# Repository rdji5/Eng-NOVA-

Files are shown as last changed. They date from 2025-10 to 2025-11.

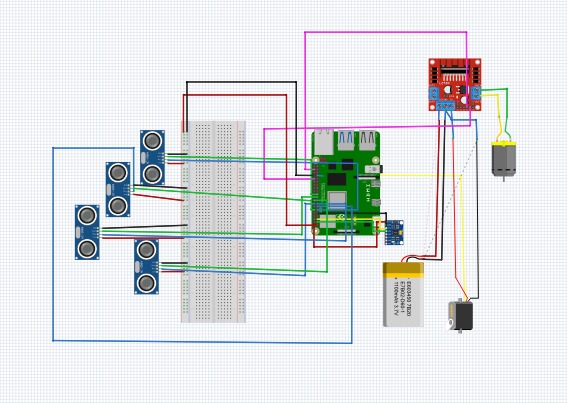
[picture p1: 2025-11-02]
Schemes/Electronic circuit.jpg

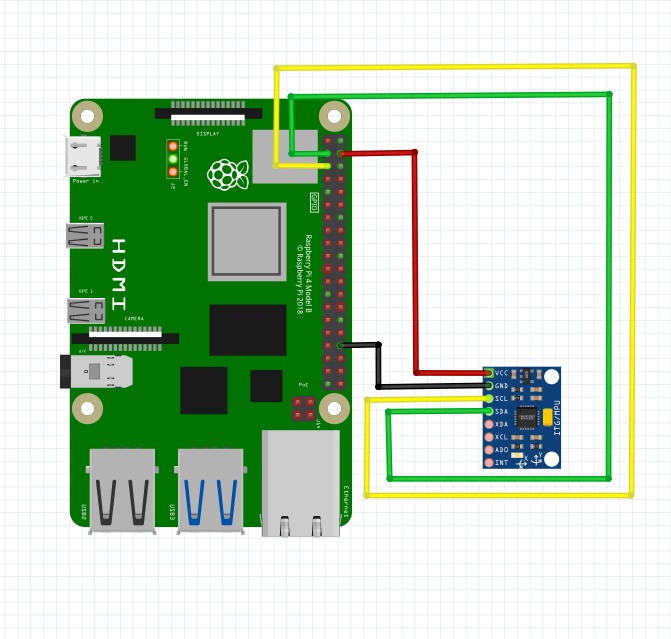
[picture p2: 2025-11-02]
Schemes/gyro.jpg

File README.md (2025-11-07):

# NOVA-Future-Engineers
### ***We Are The NOVA Engineers Team***

</p>
<p align="center">
Nova symbol
</p>

You can follow our team on social media to stay updated with our latest projects and achievements.
We share behind-the-scenes moments, progress updates, and highlights from our journey in robotics and technology.
Follow us on:

- Instagram [click here](https://www.instagram.com/nova_engineer3?)
- Facebook [click here](https://www.facebook.com/share/1Cu9dFqsgs/)

# Content
`3DModels` This folder has the robot’s 3D design and the final rendered version

`Car Pictures` This folder contains images of the robot car captured from six different angles, providing a complete visual overview of its design and structure

`Document (PDF form)` Includes a short document with project info from GitHub, saved as a PDF for A4 printing

`FlowChart` This folder includes flow diagrams that represent the logic and structure of the robot’s control system, showing how it interprets sensor data and executes movement decisions during tasks.

`Mechanical parts` parts Contains all mechanical parts used in our robot

`Problems`Documents the problems encountered during the project and their corresponding solutions.

`Tables` This folder includes all the tables we used in our project, such as time plans, task schedules, and data organization charts.

`Program` Contains all the code we wrote for the WRO 2025 Future Engineers and some charts that explain it.

`Robot-Photos` Includes multiple photos of the robot from various angles — top, side, and bottom — to provide a full visual overview of the design.

`Schemes`Drawings that show how the robot’s parts and wires are connected.

`To him work` Explains how the robot works

`Videos` Contains links to videos demonstrating how the robot performs and completes both missions successfully.

`Readme`This README file is divided into four main sections for better organization and understanding of the project’s structure.

  - [About Us](#part-1-about-us)
  - [Mechanical Design](#part-2-mechanical-design)
  - [Obstacle Management](#part-3-obstacle-management)
  - [Python Programming and Libraries](#python-programming-and-libraries)

***

### **Documentation Video (Youtube Link)**
This video is made with great care and dedication. It compiles all the information we included in the document
 you can [click here](https://youtu.be/SLGodH19J2s?si=U5ZjNuILHaWop1Gw ) to view the video we created.

***

# **Part 1: About Us**

## **This is our team**

We are three students from Hebron, Palestine, and we belong to the Programming and Artificial Intelligence clubs under the guidance of our coach, Abeer Al-Jabari. Our team was established with our participation in the Future Engineer program on September 1st. We have also previously participated in programming and STEM clubs.

## **Team name**
The name “NOVA” represents a new star that suddenly shines with renewed energy — symbolizing innovation, brilliance, and growth. It reflects our team’s spirit of creativity and ambition, as we strive to illuminate the field of engineering and technology with fresh ideas that drive progress and inspire excellence.

team photo

<hr>

## **Introduction to our team**

We are a group of passionate students participating in the Future Engineer competition  
Our goal is to learn, build, and showcase our creativity through robotics and programming
Our team works to distribute tasks in an organized manner that ensures the integration of efforts and the effective achievement of project objectives

**Raghad Wissam Al-Jaabari** 
- From Hebron
- 16 years old
- My hobbies are horse riding and badminton
-  Responsible for assembling the robot and executing programming tasks, integrating mechanical components with software to achieve the required performance and ensure the system operates efficiently
- ragadaljabari1@gmail.com

ragad aljabari

**Rasha Islam Al-Fakhouri**
- From Hebron
- 15 years old
- I love reading literature and philosophy, and I enjoy playing badminton
- Responsible for technical and organizational aspects, participated in presenting changes in project structures, in addition to continuous follow-up between stops to clarify the overall vision
- rashfakh9@gmail.com

Rasha AlFakhouri

**Layan Yousri Amro**
- From Hebron
- 14 years old
- my hobbies are sports and handicrafts
- She is responsible for documenting and writing reports on the project, and works on organizing the content and accurately documenting the work stages and results to present them in a professional and clear manner
- amrolayan95@gmail.com

layan amro

Despite our different ages and personal interests, we share a common passion: a love for technology and robotics, and a continuous desire to learn and improve. This passion drives us to participate in the Future Engineer competition and work together as a team

<hr>

### **Our Vision and Goal**
Our vision is to develop an intelligent robot capable of performing smart commands independently. We aim to build a system that can analyze its surroundings, make decisions, and complete tasks efficiently without direct human control. This project represents our first step toward creating innovative solutions that support our community and inspire future technological advancements Through this competition, we have gained valuable experience in robotics, programming, and teamwork. We also developed essential skills such as critical thinking, creativity, and planning In the future, we plan to use what we’ve learned to improve our projects, support younger students, and continue developing technologies that make a positive impact 

</p>

### **Work Schedule**

</p>

We developed a work plan to organize our steps and manage tasks within the team. It outlines what needs to be done each day, helping us set priorities, track our progress, and work with focus and teamwork to achieve our goals efficiently and accurately:
Plan_schedule

<hr>
</p>

# **Part 2: MECHANICAL DESIGN**
 ### **Firstly, the structure of the robot**
- **This car is a self-assembled (DIY) model that is built on a metallic chassis and uses an Ackermann Steering system to simulate the motion of real cars
The components of the car were connected and operated using a Raspberry Pi, programmed in Python to control movement and steering**

**This is the chassis**

<!-- Chassis Image -->
<table align="center">
  <tr>
    <td align="center">
      Chassis
      <p><b>Chassis</b>
    </td>
  </tr>
</table>

- Watch this video from the manufacturing source  [click here](https://www.youtube.com/watch?v=w_RRwR02S6U)

<div align="center">
  
</div>

<hr>
</p>

**Car size**

<!-- Car Size Image -->
<table align="center">
  <tr>
    <td align="center">
      Car Size
      <p><b>Car Size</b>
    </td>
  </tr>
</table>

<hr>
</p>

- **This car is not a remote-controlled vehicle; rather, it is an experimental platform developed to apply the principles of mechanics, control, and programming in the field of intelligent vehicles.
Thanks to the use of the Ackermann Steering system, the car replicates the actual steering mechanism of real vehicles, unlike the differential steering systems used in many traditional robots**
- **The car was entirely assembled and programmed manually as part of participation in the Future Engineer competition, using the Raspberry Pi platform**

<hr>
</p>

### **Ackermann Steering**

- **This is the servo that controls the wheels using the Ackermann Steering system:**

<!-- Ackermann Steering Image -->
<table align="center">
  <tr>
    <td align="center">
      Ackermann Steering
      <p><b>Ackermann Steering</b>
    </td>
  </tr>
</table>

Ackermann Steering Geometry: Precision Path Management
The chassis design of our autonomous vehicle is fundamentally based on the Ackermann Steering Geometry. We implemented a custom-modified version of this linkage system to ensure optimal cornering performance.
1. Principle of Operation
Unlike simpler steering methods (like skid steering), the Ackermann principle ensures that during a turn, the steering axis of all four wheels intersects at a single, momentary center point. This is achieved by ensuring the inner wheel (the wheel closer to the turn’s center) rotates at a sharper angle than the outer wheel.
This difference in rotation angle is critical because it forces the wheels to follow four distinct radii, allowing the inner wheel to travel a shorter path and the outer wheel a longer path, preventing any lateral slippage.
In our RWD system, the front wheels execute the steering motion around their respective pivots, while the single DC motor drives the non-steering rear wheels.

2. Mathematical Description (The Ideal Geometry)

<!-- Ackermann Image -->
<table align="center">
  <tr>
    <td align="center">
      Ackermann
      <p><b>Ackermann</b> 
    </td>
  </tr>
</table>

This diagram illustrates the Ideal Ackerman 
Steering Geometry. This geometry ensures that all four wheels, when steered, trace concentric circles around a single, common point, the Ackerman Center (C_a).
This fundamental relationship is governed by the vehicle's fixed dimensions—the Track Width (T) and the Wheelbase (W)—and the required steering angles:
cot(a_o) - cot(a_i) = T/W
Where a\_i is the inner wheel steering angle and a\_o is the outer wheel steering angle.
In this ideal setup:
The Inner Wheel Angle (a\_i) is always greater than the Outer Wheel Angle (a\_o) (a\_i > a\_o).
The lines drawn perpendicular to the plane of each wheel intersect precisely at C_a, ensuring all wheels roll without excessive side-slip.
Note: Real-world steering systems use a Modified Ackerman principle to optimize performance across the entire steering range, deviating slightly from this ideal formula.

3. Advantages for Our Robotic System:
Implementing the Ackermann geometry was a strategic choice that provided several specific benefits essential for the competition requirements:
Elimination of Tire Slippage: The main advantage is the prevention of tire scrubbing and slippage, which is crucial for accurate path following and maintaining maximum traction on the carpet surface.
Precise Path Management: The system offers high control over the front wheel's angle, allowing for precise steering control necessary to navigate between colored obstacles and adhere to strict course boundaries.
Single-Motor Compliance: This configuration naturally supports the requirement of using only a single DC motor for propulsion, simplifying the mechanical drivetrain while maintaining high maneuverability
Watch this video to understand the system [click here](https://www.youtube.com/watch?v=sF-PfAu50Fo)
<div align="center">
  
</div>

- **Wheels**

The wheels of this smart robot car have specific material and performance characteristics:
Wheel Rims (Hubs): The rim material is ABS (Acrylonitrile Butadiene Styrene). They are purely aesthetic
Tires (Rubber): The tire material is Rubber
Performance: The rubber material provides a large coefficient of friction and strong grip (traction) force. This design is crucial for stable and controlled movement across different surfaces
Internal Structure: All tires are internally fitted with a foam lining (insert). This foam insert provides necessary support and structure to the soft rubber tire, which is essential for consistent performance and shock absorption in RC and robot cars

<table align="center">
  <tr>
    <td align="center">
      Robot Car Gears
      <p><b>Wheels</b> 
    </td>
  </tr>
</table>

<hr>
</p>

- **Robot Car Gears**

In our project, we replaced the large gears with smaller gears in the robot car to control its movement speed
Gears are mechanical parts that transfer motion and rotation from the motor to the wheels, affecting both speed and torque
By replacing the large gears with smaller ones, we were able to reduce the car's speed and increase control accuracy, especially when performing precise movements or working with the distance sensor and relay.
- This modification helped make the car's movement more stable and safe, while maintaining the motor's power to drive the wheels smoothly

<!-- Additional Image -->
<table align="center">
  <tr>
    <td align="center">
      Additional Image
      <p><b>Robot Car Gears</b>
    </td>
  </tr>
</table>

***

<!-- BOM Image -->
<table align="center">
  <tr>
    <td align="center">
      BOM
      <p><b>BOM</b>
    </td>
  </tr>
</table>

### 📦 Bill of Materials (BOM)

| Part Name | Quantity | Description |
|---|---|---|
| Front metal chassis plate | 1 pcs | Front base for Ackermann steering system |
| Rear metal chassis plate | 1 pcs | Rear base for motor mounting |
| Electronics mounting plate | 1 pcs | Plate for Arduino / controller installation |
| Rubber wheels | 4 pcs | High-traction rubber wheels |
| Suspension spring | 1 pcs | Simple shock absorption system |
| Motor/servo mounting bracket | 1 pcs | Holder for servo or steering mechanism |
| Pulley / gear wheels | 2 pcs | Used in steering / drive linkage |
| Metal rods | Several | Used for steering linkage and frame connection |
| Bearings | Several | To reduce friction and improve smooth steering |
| Rod ends / ball joints | 4 pcs | Steering linkage endpoints |
| Servo mount brackets | 2 pcs | For attaching the steering servo |
| Metal steering arm | 1 pcs | Transfers servo motion to the wheels |
| Servo motor | 1 pcs | Controls front wheel steering |
| Spacer washers | 4 pcs | To maintain spacing between plates |
| Hex standoffs | Multiple | Structural support and spacing |
| L-shaped brackets | 2 pcs | Support brackets for structure |
| Screws (M2 / M3 assorted) | Set | Used for assembly |
| Nuts (M2 / M3 assorted) | Set | Used with screws |
| Metal shafts / pins | Multiple | For wheel/steering mechanism |
| Bearings housings | 2 pcs | Mounting for wheel axles |
| Plastic components | Several | Mechanical support parts |

<hr>
</p>

<table align="center">
  <tr>
    <td align="center">
      BOM
      <p><b>Brass Hex Standoffs</b> 
    </td>
  </tr>
</table>

- **Brass Hex Standoffs** 

These brass hex standoffs are used to elevate and support the Raspberry Pi and other electronic components.
They provide extra stability, improve airflow, and help organize the structure of the robot.
We used them to raise the robot’s layers securely, and they come in different sizes depending on the design requirements.

<hr>
</p>

### **Secondly, 3D model pieces**

- **3D machine**

**Creality Ender 5S1**

<!-- Creality Ender 5 S1 Image -->
<table align="center">
  <tr>
    <td align="center">
      Creality Ender 5 S1
      <p><b>Creality Ender 5 S1</b>
    </td>
  </tr>
</table>

The Ender-5 S1 is an FDM 3D printer with a stable cube-frame structure. It was designed to deliver better performance than previous models in the Ender series, offering faster and more responsive printing capabilities.
It is considered a great option for hobbyists and medium-level prototyping, thanks to its advanced features such as motion acceleration, direct-drive extrusion, and automatic bed-leveling support

#### General Specifications

| Specification | Value |
|---|---|
| Build Volume | 220 × 220 × 280 mm |
| Nozzle Diameter | 0.4 mm (standard) |
| Hotend Type | All-Metal |
| Max Hot-End Temperature  | 300 °C |
| Filament Diameter | 1.75 mm |
| Supported Filaments | PLA, PETG, TPU, ABS, ASA |
| Extruder Type | Sprite Direct-Drive Dual Gear Extruder |
| Max Printing Speed | 250 mm/s |
| Max Acceleration | 2000 mm/s² |
| Frame Type | Cube-frame Cartesian |
| Auto Bed Leveling | CR-Touch |

### Build Plate Specifications 

| Specification | Value |
|---|---|
| Build Plate Surface | Spring steel sheet with PEI coating (magnetic flexible plate) |
| Build Plate Size | 235 × 235 mm |
| Max Build Plate Temperature | Up to 110 °C |
| Heating Method | AC/Heatbed (magnetic heated bed) |
| Compatibility | Compatible with PC/PEI/Glass plates (optional upgrades available) |

### Tool Head Specifications 

| Specification | Value |
|---|---|
| Max Speed | 500 mm/s |
| Max Acceleration | 20 m/s² |

### Physical Dimensions 

| Specification | Value |
|---|---|
| Printer Dimensions | 425 × 460 × 570 mm |
| Package Size | 578 × 474 × 340 mm |
| Net Weight | 12.2 kg |
| Gross Weight | 14.7 kg |

### Electrical Requirements 

| Specification | Value |
|---|---|
| Voltage | 100–240 VAC |
| Frequency | 50/60 Hz |
| Rated Power | ~350W |
| Power Supply Output | 24V DC |

<hr>

#### **Filament**: Polylactic Acid or simply known as **PLA**  
<!-- PLA Filament Image -->
<table align="center">
  <tr>
    <td align="center">
      PLA Filament
      <p><b>PLA Filament</b> 
    </td>
  </tr>
</table>

PLA (Polylactic Acid) is one of the most widely used filaments in 3D printing. It is a biodegradable thermoplastic derived from renewable resources such as cornstarch or sugarcane. PLA is favored for its ease of printing, low warping, and minimal odor, making it ideal for FDM (fused deposition modeling) 3D printers. This filament is best suited for prototyping, decorative items, and educational projects, offering good strength and surface finish.  

**Diameter:** 0.75 mm  
**Printer Compatibility:** Most FDM 3D printers, including Creality Ender-5 S1

<hr><br>

**Ultrasonic holder**

- We encountered an issue with the ultrasonic sensor readings due to instability during operation. To address this, we designed a custom 3D-printed mount to securely hold the sensor in place

After implementing this design, the ultrasonic readings became significantly more stable and accurate

The final design is shown below:
<table align="center">
  <tr>
    <td align="center">
1 3d

 <p><a href="https://github.com/rdji5/Eng-NOVA-/blob/main/3D%20model/Ultrasonic%20Holder%20(1).stl" target="_blank">Click here to view 3D model.</a></p>
  </tr>
</table>

**Camera holder**
- Similarly, we faced a challenge in determining the optimal placement for the camera. To solve this, we designed a special 3D-printed mount that allowed us to position the camera securely and achieve the desired angle for accurate image captur

The final designs are shown below:

<table align="center">
  <tr>
    <td align="center">
camera

 <p><a href="https://github.com/rdji5/Eng-NOVA-/blob/main/3D%20model/Cameraa.stl" target="_blank">Click here to view 3D model.</a></p>
  </tr>
</table>

<hr>
</p>

### **Third, parts of the robot**
- **Robot mind**

###  Raspberry Pi 4 — Main Processing Unit (MPU)

The **Raspberry Pi 4 Model B** serves as the **Main Processing Unit (MPU)**, acting as the robot’s central brain.  
It executes the complex Python code and coordinates all real-time sensory data and actuator commands.

We selected the **Raspberry Pi 4** for its **quad-core Arm Cortex-A72 processor (1.8 GHz)** and **64-bit architecture**, providing a reliable balance between performance and efficiency for real-time robotic applications.  

Its computational power enables the system to simultaneously handle:  

- **Computer Vision (CV):** Processing real-time video frames from the USB camera using the OpenCV library to detect and track colored obstacles.  
- **Sensor Fusion:** Integrating data from the IMU (gyroscope) and the ultrasonic sensors for path correction and obstacle avoidance.  
- **Peripheral Control:** Managing multiple modules such as relays, motors, and sensors through the GPIO interface with stable performance.  

In compliance with competition rules, the code is **preloaded onto the Raspberry Pi 4** before the start.  
The autonomous routine is initiated by a **physical push button** connected to a GPIO pin, which activates the main Python script.  

---

**References:**  
- [Raspberry Pi 4 Product Brief (Official Datasheet)](https://datasheets.raspberrypi.com/rpi4/raspberry-pi-4-product-brief.pdf)  
- [RaspberryTips — Raspberry Pi 4 Review](https://raspberrytips.com/raspberry-pi-4-overview/)

<!-- Robot Mind Image -->
<table align="center">
  <tr>
    <td align="center">
      Robot mind
      <p><b>Raspberry Pi 4 </b>
    </td>
  </tr>
</table>

###  Raspberry Pi 5 — Main Processing Unit (MPU)

The **Raspberry Pi 5** serves as the **Main Processing Unit (MPU)**, acting as the robot’s central brain.  
It executes the complex Python code and coordinates all real-time sensory data and actuator commands.

We selected the **Raspberry Pi 5** for its **high-performance quad-core Arm Cortex-A76 processor (2.4 GHz)** and **64-bit architecture**, delivering approximately **2×–3× the CPU performance** of the previous generation.  

Its computational power is essential, providing the necessary capacity to simultaneously manage:  

- **Computer Vision (CV):** Processing real-time video frames from the USB camera using the OpenCV library to detect and track colored obstacles.  
- **Sensor Fusion:** Rapidly integrating data from the IMU (gyroscope) and the four ultrasonic sensors for path correction and obstacle avoidance.  
- **High-Speed I/O:** Equipped with the new **RP1 I/O controller (south-bridge)**, offering improved USB and storage throughput to ensure minimal latency in peripheral responses.  

In compliance with competition rules, the code is **preloaded onto the Raspberry Pi 5** before the start.  
The entire autonomous routine is initiated by a **physical push button** connected to a GPIO pin, which activates the main Python script.  

---

**References:**  
- [Raspberry Pi 5 Product Brief (Official Datasheet)](https://datasheets.raspberrypi.com/rpi5/raspberry-pi-5-product-brief.pdf)  
- [RaspberryTips — Raspberry Pi 5 Performance Overview](https://raspberrytips.com/raspberry-pi-5-review/)

<!-- Raspberry Pi 5 Image -->
<table align="center">
  <tr>
    <td align="center">
      Raspberry Pi
      <p><b>Raspberry Pi 5 </b>
  </tr>
</table>

###  Raspberry Pi 4 vs Raspberry Pi 5 Comparison

| Feature | Raspberry Pi 4 Model B | Raspberry Pi 5 |
|---|---|---|
| **Processor** | Quad-core ARM Cortex-A72 @ 1.8 GHz | Quad-core ARM Cortex-A76 @ 2.4 GHz |
| **Architecture** | 64-bit | 64-bit |
| **CPU Performance** | Baseline | ~2×–3× faster than Pi 4 |
| **GPU** | VideoCore VI | VideoCore VII (improved graphics performance) |
| **RAM Options** | 2GB, 4GB, 8GB LPDDR4 | 4GB or 8GB LPDDR4X |
| **Storage** | microSD card | microSD card + PCIe 2.0 (via FPC connector) |
| **USB Ports** | 2 × USB 3.0, 2 × USB 2.0 | 2 × USB 3.0, 2 × USB 2.0 (faster bus) |
| **GPIO** | 40-pin header | 40-pin header (same pinout) |
| **Networking** | Gigabit Ethernet, Wi-Fi 5, Bluetooth 5.0 | Gigabit Ethernet, Wi-Fi 5, Bluetooth 5.0 |
| **Video Output** | 2 × micro HDMI (4K @ 60 fps) | 2 × micro HDMI (dual 4K @ 60 fps) |
| **I/O Controller** | USB controller integrated on main SoC | Dedicated RP1 I/O controller (higher bandwidth) |
| **Power Connector** | USB-C (5 V / 3 A) | USB-C (5 V / 5 A, higher current support) |
| **Operating Temperature** | 0 – 50 °C | 0 – 50 °C (improved thermal management) |
| **Launch Year** | 2019 | 2023 |

---

**Summary:**  
Raspberry Pi 5 delivers **significantly higher CPU and GPU performance**, improved **I/O speed**, and **better responsiveness** — making it ideal for robotics, computer vision, and real-time control applications.

- **Motor Driver L298N**

L298N Dual H-Bridge Motor Driver: The Power Bridge
The L298N module serves as an essential protective and intermediary power stage between the robot's battery and its drive motor.
The Necessity of a Driver:
The Raspberry Pi (our main controller) operates using low-power signals and cannot safely source or sink the high current required by the DC propulsion motor. Attempting to connect the high-power battery circuit directly to the Pi's low-voltage GPIO pins would result in immediate and irreversible damage to the controller. Therefore, the primary role of the L298N is to act as a current amplifier and insulator, safely handling the large electrical load demanded by the motor.
How the System Works (The Dam Analogy):
The L298N can be visualized as a large, reinforced concrete dam built to manage the powerful current flowing from the 9V battery (the reservoir) to the motor (the turbine). The Raspberry Pi acts as the control mechanism that precisely regulates the dam's sluice gates (via PWM signals). The Pi merely sends low-voltage commands to the L298N, instructing when and how much of the high-power battery current should be directed to the motor, without ever having to handle the power itself.
Component Description:
This module is based on the widely used L298 Dual H-Bridge Integrated Circuit. While the board is capable of controlling two DC motors independently (up to 2A peak current each), our application utilizes only one motor port to drive our single-motor RWD system. The unit is optimized for microcontroller interfacing, requiring only a few digital lines for full control. The board also features essential integrated components, including LED power indicators, internal protection diodes, and an onboard +5V voltage regulator which can supply power to the low-voltage controller (like the Raspberry Pi) for convenience.
Key Technical Data:
- Driver: L298N Dual H-Bridge DC Motor Driver
- Operating Voltage Range: DC 5 V - 35 V (Motor Power)
- Peak Current: 2 Amp per motor
- Input Logic Voltage (Control Signal): 
- Low: -0.3 ≤ Vin ≤ 1.5V (control signal is invalid).
- High: 2.3V ≤ Vin ≤ Vss (control signal active).
- Maximum Power Dissipation: \text{20W} (at T = 75^\circ C)
- On-board Feature: Integrated +5V regulated output supply.
- Approximate Dimensions: 4.3cm × 4.3cm × 2.7cm
<!-- Motor Driver L298N Image -->
<table align="center">
  <tr>
    <td align="center">
      Motor Driver L298N
      <p><b>Motor Driver L298N</b>
    </td>
  </tr>
</table>

- **Motor DC**

This motor belongs to the class of DC Geared Motors, specifically the JGA25-370 series, known for providing a necessary trade-off between speed and torque for robotics and automation applications. It is designed to be highly compatible with popular microcontroller platforms such as Arduino, Raspberry Pi, and STM32, utilizing common DC motor driver modules.
- Model Name and Type: JGA25-370 DC Gear Motor. The name implies a 25mm gearbox diameter attached to a 370 series motor.
- Operating Voltage: The nominal operating voltage is 12V DC.
- Output Speed (No-load): It provides an output speed of 210RPM (Revolutions Per Minute) under no-load conditions.
- Torque Capability: The motor delivers up to 12Kg • cm of torque. This makes it suitable for medium-load mechanical motion control projects.
- Gearbox Material: It features a durable all-metal gearbox for enhanced strength and long service life, ensuring stable and reliable continuous operation.
- Output Shaft: The typical output shaft diameter is 6mm.
- Typical Applications: This motor is ideal for building robots, conveyor systems, smart vehicles, and other DIY projects requiring controlled motion.
- Stall Current: The internal motor (before the gearbox) can draw a Stall Current (maximum current draw when the shaft is blocked) of approximately 2.2 Amps at 12V.
- Motor Driver Requirement: This means the chosen motor driver (the module linking the motor to the Raspberry Pi) must have a continuous current rating exceeding 2.2 Amps per channel to safely operate the motor, especially when the car is starting or pushing against an obstacle.
2.3.2) Encoder:
    The motor comes integrated with an encoder to provide closed-loop control of speed and position, which is essential for precise robotic applications.
1) Encoder Type and Output Signal:
- The integrated encoder uses Hall Sensor technology.
- It provides two square wave outputs, designated as Channel A and Channel B.
- The signals are approximately 90° out of phase. This phase difference is crucial for determining the direction of rotation (quadrature encoding).
- The voltage output of the Hall sensor signals ranges from 0V to Vdc (the encoder's supply voltage).
3) Wiring and Physical Characteristics:
- Leads: The encoder assembly is terminated by 6 color-coded leads.
- Connector: These leads are typically terminated into a 6 female header with a 0.1''pitch (standard spacing).
- Length: The lead length is approximately 15cm.
- Mounting: The motor faceplate includes 2 mounting holes for M3 screws. The distance between these mounting holes is 18mm apart.
4) Wire Function (Based on common JGA25-370 Encoders):
- The 6 wires generally correspond to:
1)	Two Wires (Motor): For the 12V motor power (e.g., Red/White or Red/Black).
2)	Four Wires (Encoder): VCC (Encoder Power, usually 5V or 3.3V), GND, and the two signal lines (Channel A and Channel B).
<!-- Motor DC Image -->
<table align="center">
  <tr>
    <td align="center">
      Motor DC
      <p><b>Motor DC</b>
    </td>
  </tr>
</table>
<!-- Encoder Image -->
<table align="center">
  <tr>
    <td align="center">
      Encoder
      <p><b>Encoder</b> 
    </td>
  </tr>
</table>

- **Servo Motor**

Precise Steering Actuator
The Servo Motor is the critical actuator responsible for translating the path-planning commands from the Raspberry Pi into physical steering motion.
1. Integration with Ackermann Geometry
Function: The servo is connected via a custom linkage to the front wheels, enabling the precise, differential steering angles required by the Ackermann Steering Geometry.
Model: Based on its characteristics (and likely MG996R designation), the model used is a Digital, High-Torque Servo with Metal Gears. The high torque rating (~ 10kg ٠ cm) ensures sufficient force to overcome the mechanical friction and maintain the steering angle under load.
2. Control and Power
Control Protocol: The servo angle is precisely controlled by sending Pulse Width Modulation (PWM) signals from the Raspberry Pi's GPIO header. The duration of the pulse dictates the angular position of the angular position of the wheel.
Power: The servo requires a stable operating voltage typically in the 5V  -  6V range. This power is reliably supplied by the Step-down Module (Voltage Regulator), ensuring steady operation independent of the main 9V battery fluctuations
<!-- Servo Motor Image -->
<table align="center">
  <tr>
    <td align="center">
      Servo Motor
      <p><b>Servo Motor</b>
    </td>
  </tr>
</table>

- **voltage regulator XL4015**

The DC-DC Step-down Module is a non-isolated buck converter based on the widely used LM2596 integrated circuit. It serves as a crucial power conditioning component, managing the transition from the high-power drive system to the sensitive control electronics.
1. Power Regulation Necessity
The robot's propulsion system operates on a 9V battery supply, necessary for the  DC drive motor. However, the sensitive low-voltage components—namely the Raspberry Pi 4 5V/3A minimum), the Servo Motor, and all digital Sensors—require a stable and lower operating voltage.
The primary function of this module is to safely and efficiently step-down the 9V input voltage to a regulated 5V output. This prevents potential damage to the control board and ensures power stability, which is vital for the reliable operation of the Raspberry Pi's CPU and GPIO communications.
2. Key Operational Data
The module accepts a wide input range 4.5V to 40V), easily accommodating the 12V battery output. It is manually tuned to provide a precise 5V output voltage and is rated for a continuous output current of approximately 3A, providing a sufficient power budget for all low-power electronics in the system. The high conversion efficiency (> 80\%) minimizes energy loss as heat, preserving battery life
<!-- Voltage Regulator XL4015 Image -->
<table align="center">
  <tr>
    <td align="center">
      Voltage Regulator XL4015
      <p><b>Voltage Regulator XL4015</b> 
    </td>
  </tr>
</table>

- **Relay**

A relay is an electronic component used to control the switching ON or OFF of electrical circuits using a small electrical signal from a microcontroller such as the Raspberry Pi
The relay acts as an interface between low-voltage control circuits and high-voltage electrical loads
It operates on the principle of electromagnetism, containing a copper coil (Coil) that creates a magnetic field when current passes through it. This magnetic field pulls a metal armature, changing the connection state between its internal terminals:
- COM (Common): The common contact
- NO (Normally Open): Open by default and closes when the relay is activated
- NC (Normally Closed): Closed by default and opens when the relay is activated
When a signal is sent from the microcontroller to the relay, current flows through the coil, generating a magnetic field that moves the metal armature. This action switches the connected circuit ON or OFF

Relays are used to control devices that require higher current or voltage than the microcontroller can supply, such as:
- Running motors and fans.
- Turning lights or pumps on and off.
- Cutting power in safety or smart control systems.
Thus, the relay allows microcontrollers to safely and efficiently control high-power electrical systems without damaging sensitive electronic components

<!-- Relay Module Image -->
<table align="center">
  <tr>
    <td align="center">
      Relay Module
      <p><b>Relay Module</b>
    </td>
  </tr>
</table>

- **gyroscope MPU6050**

Inertial Measurement Unit (IMU): MPU-6050
The MPU-6050 Inertial Measurement Unit (IMU) serves as the primary sensor for motion and orientation tracking, correcting for mechanical and environmental inaccuracies that cannot be managed by vision or distance sensors.

1. Function and Integrated Components
The MPU-6050 is a sophisticated MotionTracking device that integrates a 3-axis gyroscope and a 3-axis accelerometer. It utilizes 16-bit Analog-to-Digital Converters (ADCs) for high-precision data capture.
- Gyroscope (Angular Rate): Measures the rate of rotation around the X, Y, and Z} axes. This is essential for detecting unwanted yaw (heading deviation) and precisely correcting the Ackermann steering angle. The range is user-programmable up to +- 2000⁰/sec.
- Accelerometer (Linear Acceleration): Measures linear acceleration and gravity, used to determine the robot's tilt angle (roll and pitch) and estimate linear distance traveled. The range is programmable up to +-16g.
- Digital Motion Processor (DMP): This integrated hardware unit processes complex 6-axis MotionFusion algorithms. Crucially, the DMP offloads computation from the Raspberry Pi by processing raw sensor data into clean, ready-to-use orientation information directly on the chip.
2. System Integration and Power
The MPU-6050 communicates with the Raspberry Pi 4 using the efficient I2C serial communication protocol. This protocol is highly efficient, requiring a minimum number of dedicated GPIO pins.
- Power: The module operates between 3V to 5V and is safely powered by the 5V} regulated output from the LM2596 module.
3. Role in Navigation
The IMU provides the core data for internal navigation (dead reckoning). Regardless of whether the system implements explicit sensor fusion with the ultrasonic sensors, the highly accurate angular rate and acceleration data are crucial for stabilizing the robot's movement and ensuring that the programmed path is maintained against physical disturbances
<!-- Gyroscope MPU6050 Image -->
<table align="center">
  <tr>
    <td align="center">
      Gyroscope MPU6050
      <p><b>Gyroscope MPU6050</b>
    </td>
  </tr>
</table>

- **Ultrasonic**

Ultrasonic Sensors (HC-SR04): Comprehensive ToF Ranging System
The robot is equipped with a total of four HC-SR04 Ultrasonic Sensors that form the primary short-range ranging system. These sensors provide the vehicle with echolocation capabilities, on par with how bats and dolphins locate objects in complete darkness and beneath the water surface. This array is fundamental for robust, real-time obstacle avoidance and precise navigation along the course boundaries.
Strategic Implementation and System Integration
The four HC-SR04 sensors are strategically positioned to maximize situational awareness: one mounted in the front, one in the rear, and one on each of the right and left sides of the chassis. This arrangement minimizes blind spots and provides the angular data necessary for advanced Sensor Fusion.
Power and Interface: The sensors require a stable +5V regulated supply, drawing less than 15mA each. Each sensor utilizes two dedicated GPIO pin (Trigger and Echo) on the Raspberry Pi for control and data acquisition.
Sensor Fusion Role: The simultaneous input from four points allows the control system to accurately determine both the distance and the angular position of an obstacle. This redundancy is vital for high-reliability autonomy, allowing the algorithm to differentiate between a critical frontal obstacle and a simple boundary wall alongside the vehicle.

Principle of Operation and Technical Specification
The HC-SR04 module operates on the principle of measuring the Time-of-Flight (ToF) of an ultrasonic sound wave.
1–Triggering: Measurement begins when the Raspberry Pi sends a minimum 10uS high pulse to the Trigger pin, prompting the transmitter to emit an 8-cycle  burst of ultrasonic sound at 40kHz.
2– Echo Reception: The sound wave reflects off an object, and the duration it takes to return is measured. The sensor outputs a high pulse on the Echo pin, the width of which is directly proportional to the distance.
3– Calculation: The Raspberry Pi measures this pulse width (time), and the distance is calculated using the formula
Distance = Speed × Time, divided by two since the time measured is for the signal's round trip.
The sensor boasts a practical measuring range of 2cm to 400cm and an accuracy that can reach 3mm. This combination of range and precision makes it perfectly suited for the short-range, dynamic obstacle avoidance challenges presented in the competition course
<!-- Ultrasonic Sensor HC-SR04 Image -->
<table align="center">
  <tr>
    <td align="center">
      Ultrasonic Sensor HC-SR04
      <p><b>Ultrasonic Sensor HC-SR04</b>
    </td>
  </tr>
</table>

- **switch**

This switch controls the connection and disconnection of power between the battery and the robot. Since the rules require cutting off power before operation, we added this switch to comply with that. We soldered the red (positive) wire to the input side of the switch and another red wire to the output side. When the switch is turned on, power flows from the battery to the step-down module and then to the rest of the robot’s components
<!-- Switch Image -->
<table align="center">
  <tr>
    <td align="center">
      Switch
      <p><b>Switch</b> 
    </td>
  </tr>
</table>

### Robot 
**This picture shows our robot in real life, displaying how it looks with all its components assembled**
<!-- Final Robot Image -->
<table align="center">
  <tr>
    <td align="center">
      Final Robot
      <p><b>Final Robot</b> 
    </td>
  </tr>
</table>

***
### Wiring Diagram and Power Distribution Diagram
- **It shows you the connection of various components to the Raspberry Pi**
<!-- B Image -->
<table align="center">
  <tr>
    <td align="center">
      B Image
      <p>Power Distribution Diagram</p>
    </td>
  </tr>
</table>

- **It shows the ports of various components connected to the Raspberry Pi, as well as the voltage levels supplied to the Raspberry Pi and its connected components**
<!-- A Image -->
<table align="center">
  <tr>
    <td align="center">
      A Image
      <p> Wiring Diagram</p>
    </td>
  </tr>
</table>

***

# **Part 3: Obstacle Management**

#  Open Challenge

##  Role of the Distance Sensor

To navigate the initial stage intelligently, we developed a dedicated algorithm that empowered the robot to make **autonomous directional decisions**.  
Before encountering the first turn, the robot was uncertain whether to proceed **clockwise** or **counterclockwise**.

We incorporated **ultrasonic sensors** into the robot’s design to provide continuous **spatial awareness**. These sensors measured the distance to nearby obstacles on both the **left** and **right** sides.

###  Sensor Logic
- **Left Sensor:**  
  If the right sensor measured a distance **greater than 160 cm**, the robot decided to move **counterclockwise**.
  <table align="center">
  <tr>
    <td align="center">
      Clockwise
      <p>This is the clockwise rotation of the robot.</p>
    </td>
  </tr>
</table>

- **Right Sensor:**  
  If the left ultrasonic sensor detected a distance **greater than 160 cm** (indicating open space on that side), the robot chose to move **clockwise**.
  
<table align="center">
  <tr>
    <td align="center">
      Counterclockwise
      <p>This is the counterclockwise rotation of the robot.</p>
    </td>
  </tr>
</table>

##  Path Stability
While traveling in a straight path, the robot maintained a **safety buffer of 20 cm** from the inner wall.  
If this distance was violated, the system automatically **adjusted its trajectory** to stay stable and balanced.

This algorithm allowed the robot to **dynamically adapt** to its surroundings — making intelligent path choices and real-time corrections, simulating a level of **spatial awareness** similar to advanced autonomous systems.

##  Lap Counting Logic
Each time the robot detected a **corner** and a **large distance (~160 cm)**, it increased its lap counter.  
After completing **12 laps** (where **1 round = 4 corners**), the robot automatically stopped at a **specific location**, marking the completion of the task.

## **Open Challenge round (Youtube Link)**

This video shows our robot completing the first round(Open Challenge), you can [click here](https://www.youtube.com/watch?v=wE9Jfp3p2G0) to view the video we created.

## **Flowchart**

OpenChallenge

***
## **Source Code**

- **Section 1 [Open Challenge round]**

**Basic Import and Initialization**

```python
import RPi.GPIO as GPIO
import time
import smbus

# Motor Pins
MOTOR_IN3 = 38
MOTOR_IN4 = 32

# Servo Pin
SERVO_PIN = 37

# Ultrasonic Sensor Pins
FRONT_TRIG = 13
FRONT_ECHO = 11
RIGHT_TRIG = 31
RIGHT_ECHO = 29
LEFT_TRIG = 10
LEFT_ECHO = 8

# Servo Angles
SERVO_STRAIGHT = 60
SERVO_RIGHT = 95
SERVO_LEFT = 10

# MPU6050 Address
MPU6050_ADDR = 0x68
bus = smbus.SMBus(1)

# Distance thresholds (cm)
DETECTION_DISTANCE = 80
DIRECTION_CHECK_DISTANCE = 360

# Movement Timing (seconds)
TURN_DURATION = 1.1
STRAIGHT_AFTER_TURN = 1.5
```

**Explanation:**
This section imports the essential libraries to control the robot, defines the GPIO pins connected to the Raspberry Pi for motors, servo, and ultrasonic sensors, sets the three servo angles, and establishes the distance thresholds.
These thresholds indicate when an obstacle is close enough to require stopping or detecting the path direction (clockwise or counterclockwise).
It also initializes communication with the MPU6050 for orientation tracking and sets basic timing values for movement and turns.

- **Section 2 [Open Challenge round]**

**GPIO, MPU6050, and Ultrasonic Initialization**

```python
def setup_gpio():
    GPIO.setmode(GPIO.BOARD)
    GPIO.setwarnings(False)
    
    # Setup motor and servo pins
    GPIO.setup(MOTOR_IN3, GPIO.OUT)
    GPIO.setup(MOTOR_IN4, GPIO.OUT)
    GPIO.setup(SERVO_PIN, GPIO.OUT)
    
    # Setup ultrasonic sensor trigger pins
    for trig in [FRONT_TRIG, RIGHT_TRIG, LEFT_TRIG]:
        GPIO.setup(trig, GPIO.OUT)
        GPIO.output(trig, False)
    
    # Setup ultrasonic sensor echo pins
    for echo in [FRONT_ECHO, RIGHT_ECHO, LEFT_ECHO]:
        GPIO.setup(echo, GPIO.IN)

def mpu6050_init():
    try:
        bus.write_byte_data(MPU6050_ADDR, 0x6B, 0)
        time.sleep(0.1)
        return True
    except:
        return False
```

**Explanation:**
setup_gpio() configures the Raspberry Pi GPIO pins for motors, servo, and ultrasonic sensors. Trigger pins are outputs and echo pins are inputs.
mpu6050_init() initializes the MPU6050 sensor to enable orientation tracking.
These steps prepare the robot’s hardware for autonomous navigation and obstacle detection.

- **Section 3 [Open Challenge round]**

**Motor Control**

```python
def motor_forward():
    GPIO.output(MOTOR_IN3, GPIO.LOW)
    GPIO.output(MOTOR_IN4, GPIO.HIGH)

def motor_stop():
    GPIO.output(MOTOR_IN3, GPIO.LOW)
    GPIO.output(MOTOR_IN4, GPIO.LOW)
```

**Explanation:**
motor_forward() makes the robot move forward by setting the motor pins appropriately.
motor_stop() stops the robot by turning off both motor pins.
These functions provide basic motor control needed for autonomous navigation.

- **Section 4 [Open Challenge round]**

**Servo Control**

```python
def setup_servo():
    global servo_pwm
    servo_pwm = GPIO.PWM(SERVO_PIN, 50)
    servo_pwm.start(0)
    time.sleep(0.1)

def set_servo_angle(angle):
    duty = 2.5 + (angle / 180.0) * 10
    servo_pwm.ChangeDutyCycle(duty)
    time.sleep(0.3)
    servo_pwm.ChangeDutyCycle(0)

def steer_straight():
    set_servo_angle(SERVO_STRAIGHT)

def steer_left():
    set_servo_angle(SERVO_LEFT)

def steer_right():
    set_servo_angle(SERVO_RIGHT)
```
    
**Explanation:**
setup_servo() initializes the servo motor for steering.
set_servo_angle(angle) sets the servo to a specific angle.
steer_straight(), steer_left(), and steer_right() position the servo to go straight, left, or right.
These functions allow precise steering control for autonomous navigation.

- **Section 5 [Open Challenge round]**

**Ultrasonic Sensor Distance Reading**

```python
def get_distance(trig_pin, echo_pin):
    GPIO.output(trig_pin, True)
    time.sleep(0.00001)
    GPIO.output(trig_pin, False)

    timeout = time.time()
    
    while GPIO.input(echo_pin) == 0:
        pulse_start = time.time()
        if pulse_start - timeout > 0.1:
            return -1

    while GPIO.input(echo_pin) == 1:
        pulse_end = time.time()
        if pulse_end - pulse_start > 0.1:
            return -1

    pulse_duration = pulse_end - pulse_start
    distance = pulse_duration * 17150
    distance = round(distance, 1)

    return distance if distance < 400 else -1

def get_front_distance():
    return get_distance(FRONT_TRIG, FRONT_ECHO)

def get_right_distance():
    return get_distance(RIGHT_TRIG, RIGHT_ECHO)

def get_left_distance():
    return get_distance(LEFT_TRIG, LEFT_ECHO)
```

**Explanation:**
These functions read distances using ultrasonic sensors.
get_distance(trig_pin, echo_pin) sends a pulse and calculates the time it takes to receive the echo, converting it into distance in centimeters.
get_front_distance(), get_right_distance(), and get_left_distance() return the distances from the respective sensors.
This allows the robot to detect obstacles and measure the space around it for autonomous navigation.

- **Section 6 [Open Challenge round]**

**Direction Detection Logic**

```python
def detect_direction():
    left_readings = []
    right_readings = []
    
    for i in range(10):
        left = get_left_distance()
        right = get_right_distance()
        
        if left > 0:
            left_readings.append(left)
        if right > 0:
            right_readings.append(right)
        
        time.sleep(0.1)

    avg_left = sum(left_readings) / len(left_readings) if left_readings else 0
    avg_right = sum(right_readings) / len(right_readings) if right_readings else 0

    if avg_left > DIRECTION_CHECK_DISTANCE:
        return 'CCW'  # Counter-clockwise
    elif avg_right > DIRECTION_CHECK_DISTANCE:
        return 'CW'   # Clockwise
    else:
        return 'CCW' if avg_left > avg_right else 'CW'
```

**Explanation:**
detect_direction() uses multiple ultrasonic readings from the left and right sensors to determine the robot's optimal turning direction.
If left side > 360 cm → move counter-clockwise (CCW).
If right side > 360 cm → move clockwise (CW).
If both < 360 cm → choose the side with more space.
This ensures the robot selects the safest and widest path during autonomous navigation.

- **Section 7 [Open Challenge round]**

**90-Degree Turn Function**

```python
def turn_90(turn_right):
    if turn_right:
        steer_right()
    else:
        steer_left()
    
    motor_forward()
    time.sleep(TURN_DURATION)
    steer_straight()
```

**Explanation:**
turn_90(turn_right) performs a 90-degree turn
If turn_right is True, the robot turns right; otherwise, it turns left.
The function moves the robot forward while turning, waits for the specified TURN_DURATION, and then resets the steering to straight.
This allows precise cornering during autonomous navigation.

- **Section 8 [Open Challenge round]**

**Navigation Logic**

```python
def navigate():
    global sections_completed, direction, running
    
    motor_forward()
    steer_straight()

    while running and sections_completed < TOTAL_SECTIONS:
        front_dist = get_front_distance()
        
        if front_dist <= DETECTION_DISTANCE and front_dist > 0:
            motor_stop()
            
            if direction is None:
                # First time detecting obstacle: wait 2 seconds and detect direction
                time.sleep(2)
                direction = detect_direction()
            else:
                # Subsequent times: short wait
                time.sleep(0.1)
```

**Explanation:**
- navigate() handles the robot's forward movement and obstacle detection.
- The robot moves forward and keeps steering straight.
- If an obstacle is detected within 80 cm (DETECTION_DISTANCE), the robot stops.
- On the first detection, it waits 2 seconds and determines the turning direction.
- On subsequent detections, it only pauses briefly (0.1 seconds)
- This logic allows safe and intelligent navigation around obstacles during the Open Challenge.

- **Section 9 [Open Challenge round]**

**Post-Obstacle Navigation and Completion**

```python
if direction == 'CW':
    turn_90(True)
else:
    turn_90(False)

motor_forward()
steer_straight()
time.sleep(STRAIGHT_AFTER_TURN)

sections_completed += 1

else:
    motor_forward()
    steer_straight()

time.sleep(0.05)

motor_stop()
steer_straight()
time.sleep(0.5)
running = False
```
**Explanation:**
After detecting a direction, the robot executes a 90-degree turn (turn_90) depending on whether it should go clockwise or counter-clockwise.
It then moves forward for 1.5 seconds (STRAIGHT_AFTER_TURN) to continue on the path.
- If no obstacles are detected, the robot simply continues straight with small adjustments.
-The sections_completed counter increases with each segment.
Once 24 sections are completed, the robot stops, resets steering, and ends the run.
This logic ensures the robot navigates through all track sections safely and autonomously.

- **Section 10 [Open Challenge round]**

**Main Function — Setup and Start**

```python
def main():
    global running
    
    try:
        # Initialize hardware
        setup_gpio()
        setup_servo()
        mpu6050_init()
        time.sleep(0.5)
        
        # Reset steering and stop motors
        steer_straight()
        motor_stop()
        
        # Start navigation
        running = True
        navigate()
```

**Explanation:**
The main() function prepares all hardware components and starts the Open Challenge.
- GPIO, servo, and MPU6050 are initialized.
- Steering is set straight and motors are stopped before starting.
- The navigate() function is called to begin autonomous movement and obstacle handling.
This ensures the robot is fully ready before starting the challenge.

<hr>

##  Strategy

In this challenge, the robot is required to complete **three full laps** around a track containing **randomly placed red and green traffic signs**.  
Each traffic sign acts as a visual cue guiding the robot’s movement along the track.

###  Traffic Sign Interpretation
- ** Red Sign:** The robot must stay on the **right** side of the lane.  

<!-- Red Line Image -->
<table align="center">
  <tr>
    <td align="center">
      Red Line
      <p><b>Red Sign Line</b> 
    </td>
  </tr>
</table>

- ** Green Sign:** The robot must stay on the **left** side of the lane.
  
<!-- Green Line Image -->
<table align="center">
  <tr>
    <td align="center">
      Green Line
      <p><b>Green Sign</b> 
    </td>
  </tr>
</table>

##  Rules and Constraints
- The robot must **not move or displace any traffic signs** during the run.  
- After completing the three laps, the robot must **locate a parking space** and perform **parallel parking** correctly.  

##  Final Objective
- Demonstrate the robot’s ability to **detect signs and make accurate decisions in real time**.  
- Maintain **stable and precise movement** while following all track rules.

## **Flowchart**

ObstacleChallenge

<hr>

## **Source Code**

- **Section 1 [Obstacle Challenge round]**

**Color Detection with Camera (LAB-based)**

```python
import cv2
import numpy as np

def normalize_color(frame):
    """Gray world color normalization to reduce lighting effect"""
    result = frame.astype(np.float32)
    avg_b = np.mean(result[:, :, 0])
    avg_g = np.mean(result[:, :, 1])
    avg_r = np.mean(result[:, :, 2])
    avg_gray = (avg_b + avg_g + avg_r) / 3

    result[:, :, 0] = np.minimum(result[:, :, 0] * (avg_gray / avg_b), 255)
    result[:, :, 1] = np.minimum(result[:, :, 1] * (avg_gray / avg_g), 255)
    result[:, :, 2] = np.minimum(result[:, :, 2] * (avg_gray / avg_r), 255)

    return result.astype(np.uint8)

# Initialize camera (USB or Pi camera)
camera = cv2.VideoCapture(0)
camera.set(3, 640)
camera.set(4, 480)

while True:
    ret, frame = camera.read()
    if not ret:
        break

    # Optional: normalize to reduce color cast from lighting
    frame = normalize_color(frame)

    # Convert BGR to LAB
    lab = cv2.cvtColor(frame, cv2.COLOR_BGR2LAB)
    L, A, B = cv2.split(lab)

    # --- Detect RED (A-channel is high for red) ---
    red_mask = cv2.inRange(A, 150, 255)   # high A → red
    green_mask = cv2.inRange(A, 0, 110)   # low A → green

    # Clean up noise
    kernel = np.ones((5, 5), np.uint8)
    red_mask = cv2.morphologyEx(red_mask, cv2.MORPH_OPEN, kernel)
    green_mask = cv2.morphologyEx(green_mask, cv2.MORPH_OPEN, kernel)

    # Find contours for red
    contours_red, _ = cv2.findContours(red_mask, cv2.RETR_TREE, cv2.CHAIN_APPROX_SIMPLE)
    for c in contours_red:
        area = cv2.contourArea(c)
        if area > 400:
            x, y, w, h = cv2.boundingRect(c)
            cv2.rectangle(frame, (x, y), (x + w, y + h), (0, 0, 255), 2)
            cv2.putText(frame, "RED", (x, y - 10), cv2.FONT_HERSHEY_SIMPLEX, 0.6, (0, 0, 255), 2)

    # Find contours for green
    contours_green, _ = cv2.findContours(green_mask, cv2.RETR_TREE, cv2.CHAIN_APPROX_SIMPLE)
    for c in contours_green:
        area = cv2.contourArea(c)
        if area > 400:
            x, y, w, h = cv2.boundingRect(c)
            cv2.rectangle(frame, (x, y), (x + w, y + h), (0, 255, 0), 2)
            cv2.putText(frame, "GREEN", (x, y - 10), cv2.FONT_HERSHEY_SIMPLEX, 0.6, (0, 255, 0), 2)

    # Display the output
    cv2.imshow("Color Detection (LAB-based)", frame)

    if cv2.waitKey(1) & 0xFF == 27:  # ESC key to exit
        break

camera.release()
cv2.destroyAllWindows()
```

**Explanation:**

- The camera captures frames in real-time and normalizes the colors to reduce lighting effects.
- Conversion to LAB color space helps separate luminance from color, improving red and green detection.
- Red and green masks are created using the A-channel of LAB.
- Morphological operations remove small noise.
- Contours are detected for each color, and bounding rectangles with labels (“RED” or “GREEN”) are drawn.
- The live frame shows the detected objects, updating in real-time.
- Press ESC to exit the program.

# **Python Programming and Libraries**
# 1.1 Python Language and Libraries Used in Our WRO Robot

## Python Language
We chose **Python** as the main programming language for our WRO robot because it is simple, powerful, and widely used in robotics and computer vision. Python allows us to write clear and organized code, making it easier to test, debug, and improve our program.  

One of the main reasons we selected Python is its strong support for the **OpenCV** library, which we used to process images and recognize objects or patterns. OpenCV gave us the ability to detect lines, colors, and QR codes — features that were essential for our robot’s mission.  

Python also works perfectly with **Raspberry Pi**, which we used as the main controller. Its flexibility allowed us to easily connect sensors and motors, and integrate the results from OpenCV to make real-time decisions.  

Using Python helped us focus on problem-solving and teamwork, since the language is easy to understand and modify. Overall, Python and OpenCV together provided a powerful combination that made our robot more intelligent and efficient during the WRO challenge.  

Python is used in our project because it is easy to learn and helps us control the robot accurately. With Python, we can program the robot’s movements, read sensor data, and analyze images from the camera. It also supports powerful libraries like **OpenCV**, **NumPy**, and more, which help us complete tasks quickly and efficiently during the competition challenges.

---

## RPi.GPIO Library
The **RPi.GPIO** library is specifically designed to interact directly with the physical world through the general-purpose input/output pins on the Raspberry Pi. Imported here as `GPIO`, its primary function is to manage the flow of digital signals.  

- You can set a pin as an **output** to send a High (1) or Low (0) signal, controlling devices like LEDs, motors, and actuators (turning them ON or OFF).  
- Conversely, you can set a pin as an **input** to read the state of physical components, such as checking whether a button has been pressed or if a sensor has detected an object.  

This library forms the foundational layer for **low-level hardware control**.

---

## OpenCV Library
**OpenCV** is a powerful and widely used library for computer vision tasks. In our WRO project, we use OpenCV to help the robot understand its surroundings through camera input.  

- It allows the robot to **detect colors**, **follow lines**, and **recognize objects or obstacles**.  
- OpenCV works well with Python and provides many ready-to-use functions that make image processing faster and easier.  

This helps improve the robot’s **accuracy** and **responsiveness** during competition challenges.

---

## time Library
The **time** library is a standard module built into Python that provides essential functions for managing time within a program. It is crucial for hardware projects, as physical devices often require specific timing to operate correctly.  

- Its most common function is `time.sleep(X)`, which pauses the execution of the program for a specified number of seconds (X).  
- This delay is vital for tasks like creating rhythmic flashing patterns, allowing mechanical components time to move into position, or stabilizing sensor readings before processing them.  
- The library also offers functions for measuring time intervals and retrieving the current time.

---

## smbus Library
The **smbus** library serves as a software interface for communicating with external devices using the **I²C (Inter-Integrated Circuit)** protocol, a very common serial communication method in embedded systems.  

- I²C allows multiple devices, such as sophisticated sensors, memory chips, and display drivers, to communicate with the Raspberry Pi using only two wires (SDA and SCL).  
- By importing `smbus`, Python code gains the ability to **address specific external chips** and send commands (write operations) or receive complex data (read operations) from them.  

This is essential for integrating advanced components that require a dedicated communication bus rather than simple ON/OFF signals.

*** 

## Tools and Applications Used

During the development of our WRO robot project, we used several applications to design, plan, and present our work efficiently:

1. **Flowchart Design – BoardMix**  
   We used **BoardMix** to create clear and organized flowcharts for our robot’s logic and program structure. This helped us plan the sequence of operations before writing the actual code.

2. **Circuit Design – Fritzing**  
   **Fritzing** was used to design and visualize the electronic circuits of the robot. It allowed us to connect sensors, motors, and other components on a virtual breadboard before physical assembly.

3. **Presentation and Background – Canva**  
   **Canva** was used to create professional backgrounds, diagrams, and visual materials for presentations and documentation, making our project visually appealing and easy to understand.

## Estimated Cost of Components

| Component | Estimated Cost (USD) |
|---|---|
| ASRC-CM-DIY Version | $142 |
| Raspberry Pi 5 Model B | $35 |
| Motor Driver L298N | $5 |
| Motor DC | $20 |
| Servo Motor | $6 |
| Voltage Regulator XL4015 | $7 |
| Gyroscope MPU6050 | $15 |
| Four Ultrasonic Sensors | $40 |
| PC i7 | $1000 |
| Smart Car Motors GA25 370 | $100 |
| **Total** | **$1370** |

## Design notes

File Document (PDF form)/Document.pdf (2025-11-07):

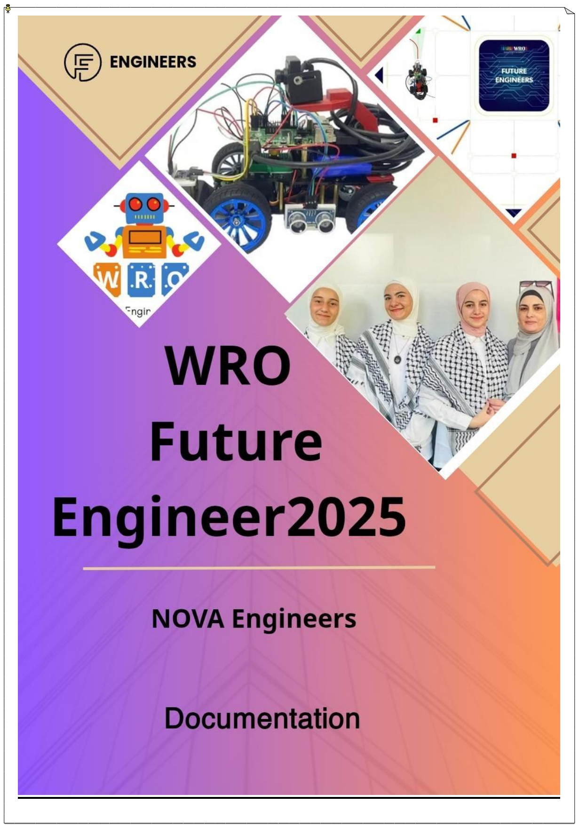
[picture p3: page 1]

Abstract:

Abstract Objective: This document outlines our strategy for the WRO Future Engineer 2025 competition, focusing on the design and program development of a vehicle capable of navigating obstacles and handling diverse challenges. Key improvements include advanced motion control, energy management, and adaptable programming, enabling responsive and efficient performance.

Methods:

To help the robot move accurately, we used advanced motion control and custom programming. We also added energy-saving methods to use power more efficiently. Regular checks are done to make sure the vehicle is ready to work. For better decision-making, the robot uses data from sensors and live camera analysis to quickly adapt to different situations.

Key Engineering Factors:

This project shows important ways to help the robot move around obstacles. It uses smart design and flexible coding so the robot can quickly react to challenges during the competition. The code and algorithms were made to help the robot work well and stay reliable in different situations.

Conclusion:

This document reflects our comprehensive engineering and programming approaches, demonstrating a commitment to excellence in the WRO Future Engineer competition through innovative design and real-time adaptability.

# Content:

CONTENT | Number

About us | )1
Work Schedule | )2
Project Estimated Cost | )3
Components of Our Robot | )4
The Diagrams | )5
Robot Photos | )6
Explanation of the rounds | )7
Flowcharts | )8
Open Challenge Code | )9
Obstacle Challenge Code | )10
Applications Used | )11

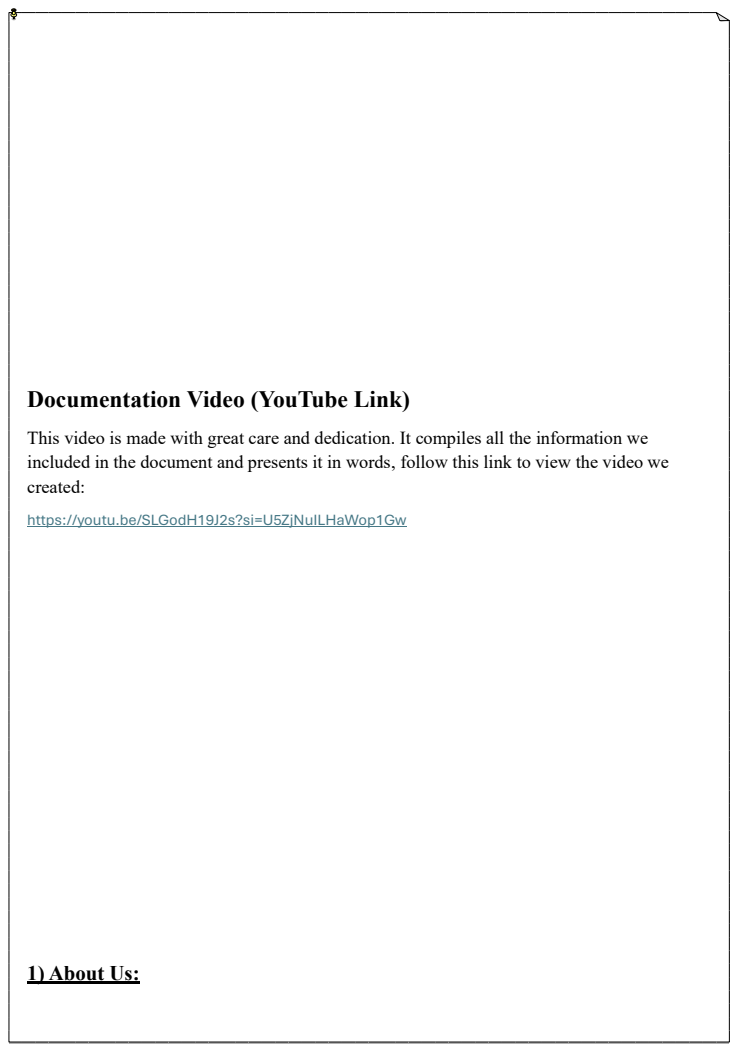
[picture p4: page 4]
1) About Us:

Documentation Video (YouTube Link)

This video is made with great care and dedication. It compiles all the information we
included in the document and presents it in words, follow this link to view the video we
created:
https://youtu.be/SLGodH19J2s?si=U5ZjNuILHaWop1Gw

The name “NOVA” represents a new star that suddenly shines with renewed energy — symbolizing innovation, brilliance, and growth. It reflects our team’s spirit of creativity and ambition, as we strive to illuminate the field of engineering and technology with fresh ideas that drive progress and inspire excellence.

Introduction to our team:

#Raghad Wissam Al-Jaabari

- From Hebron
- 16 years old
- My hobbies are horse riding and badminton
- Responsible for assembling the robot and executing programming tasks, integrating mechanical components with software to achieve the required performance and ensure the system operates efficiently

ragadaljabari1@gmail.com •

#Rasha Islam Al-Fakhouri

- From Hebron
- 15 years old
- I love reading literature and philosophy, and I enjoy playing badminton Responsible for technical and organizational aspects, participated in presenting changes in project structures, in addition to continuous follow-up between stops to clarify the overall vision
- rashfakh9@gmail.com

#Layan Yousri Amro

- From Hebron
- 14 years old
- my hobbies are sports and badminton
- She is responsible for documenting and writing reports on the project, and works on organizing the content and accurately documenting the work stages and results to present them in a professional and clear manner
- amrolayan95@gmail.com

Our Vision and Goal

Our vision is to develop an intelligent robot capable of performing smart commands independently. We aim to build a system that can analyze its surroundings, make decisions, and complete tasks efficiently without direct human control. This project represents our first step toward creating innovative solutions that support our community and inspire future technological advancements Through this competition, we have gained valuable experience in robotics, programming, and teamwork. We also developed essential skills such as critical thinking, creativity, and planning in the future, we plan to use what we’ve learned to improve our projects, support younger students, and continue developing technologies that make a positive impact.

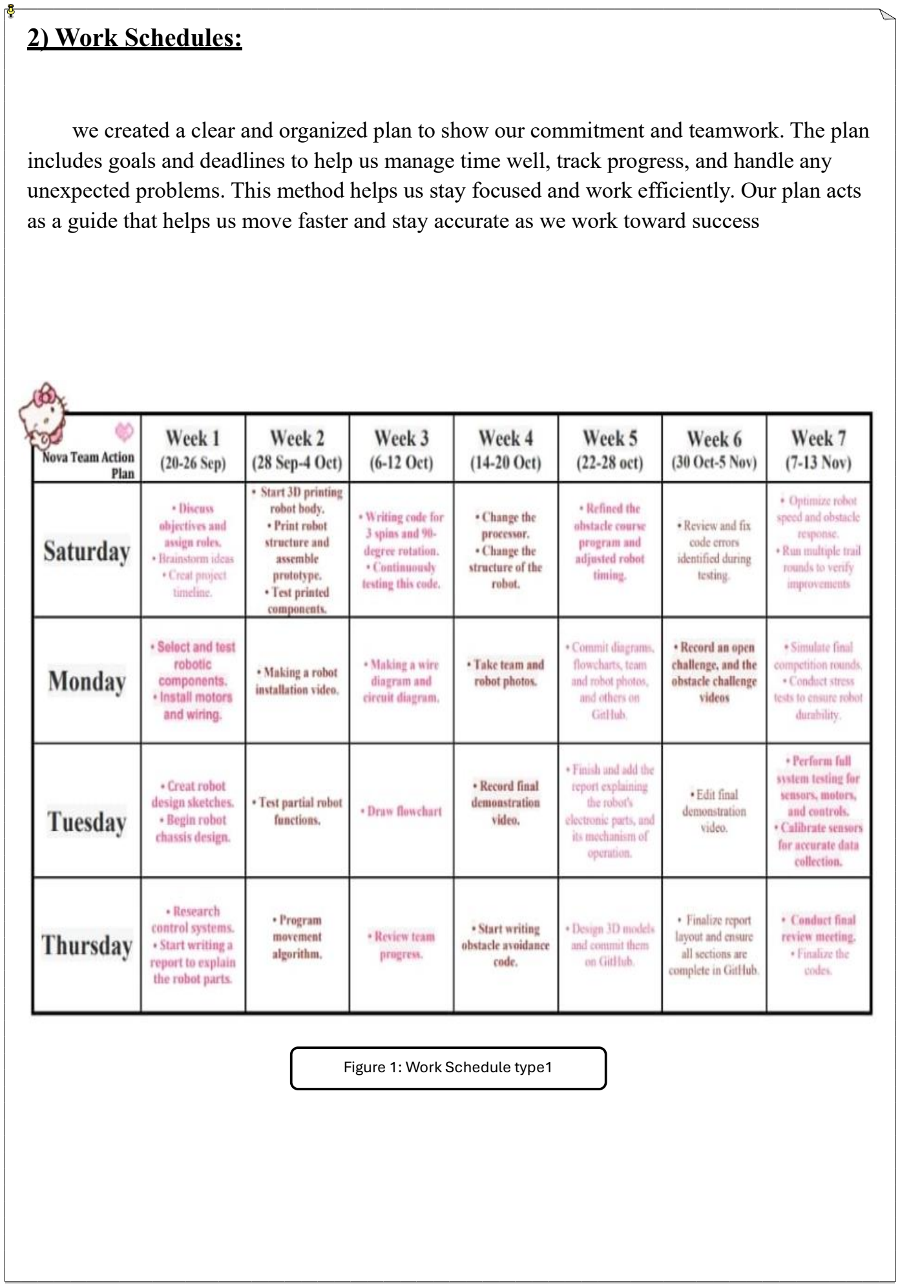
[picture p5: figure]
2) Work Schedules:; Figure 1: Work Schedule type1

we created a clear and organized plan to show our commitment and teamwork. The plan includes goals and deadlines to help us manage time well, track progress, and handle any unexpected problems. This method helps us stay focused and work efficiently. Our plan acts as a guide that helps us move faster and stay accurate as we work toward success

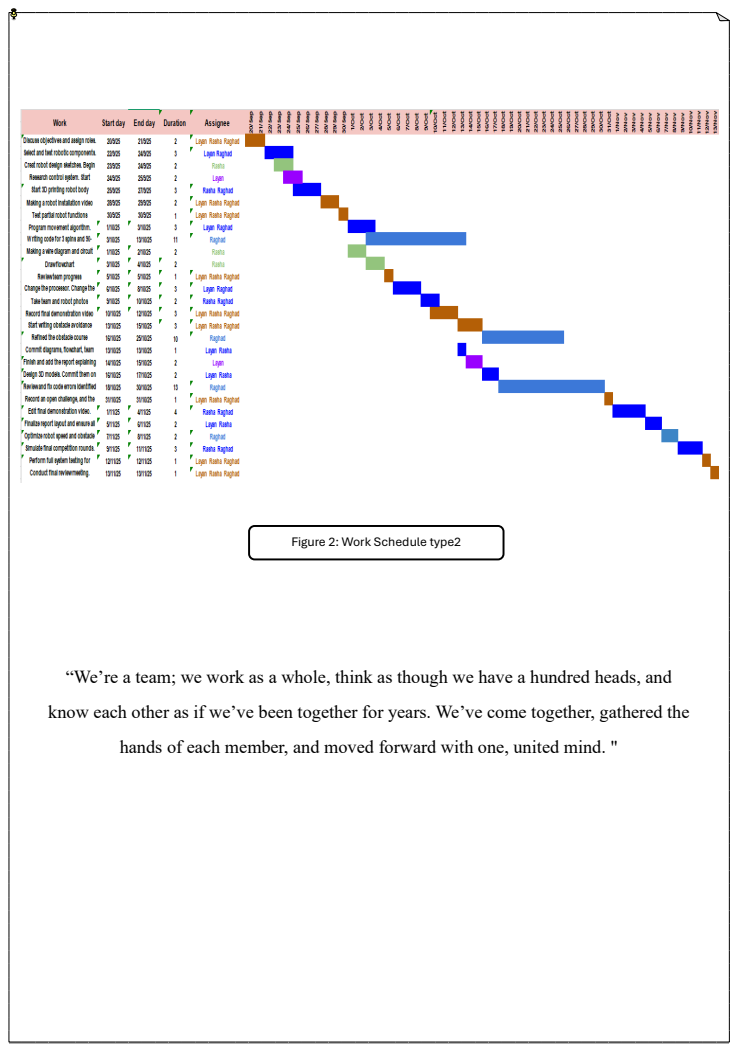
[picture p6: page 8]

Figure 2: Work Schedule type2

“We’re a team; we work as a whole, think as though we have a hundred heads, and

know each other as if we’ve been together for years. We’ve come together, gathered the

hands of each member, and moved forward with one, united mind. "

## 3) Project Estimated Cost:

## Hardware Components Estimated cost:

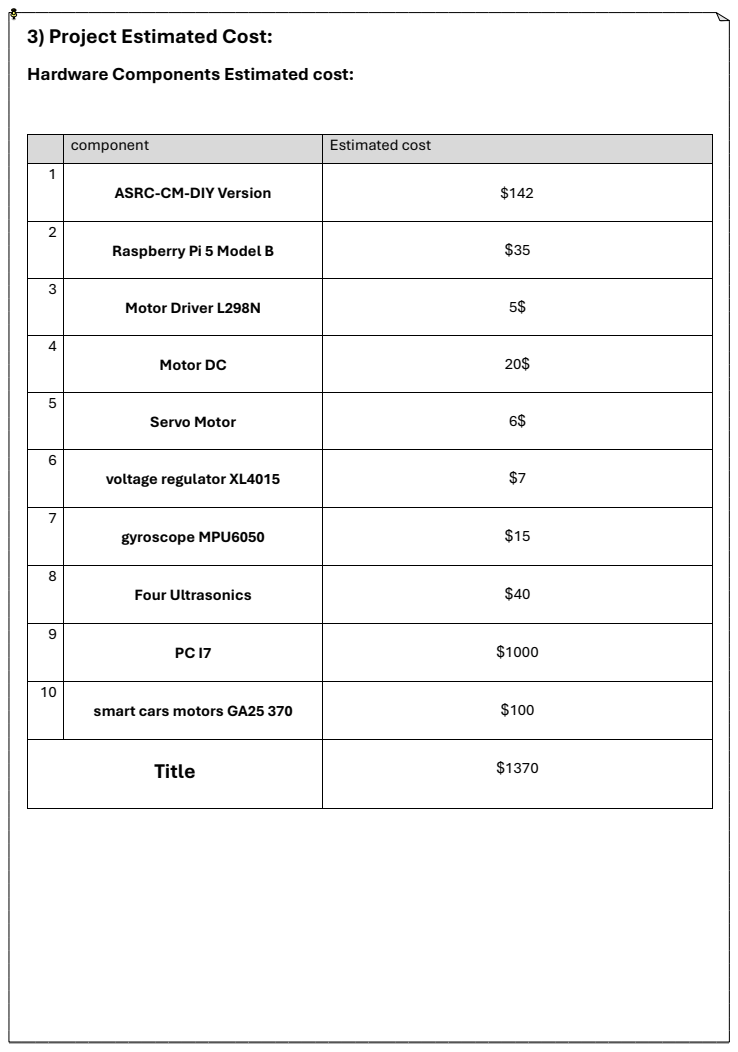
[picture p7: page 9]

component | Estimated cost
1 | ASRC-CM-DIY Version | $142

2 | Raspberry Pi 5 Model B | $35

3 | Motor Driver L298N | 5$

4 | Motor DC | 20$

5 | Servo Motor | 6$

6 | voltage regulator XL4015 | $7

7 | gyroscope MPU6050 | $15

8 | Four Ultrasonics | $40

10 | smart cars motors GA25 370 | $100

Title | | $1370

4) Components of Our Robot:

Our robot is built using several key components that help it perform tasks efficiently during the WRO competition. It includes a Raspberry Pi as the main controller, which runs the Python code and connects to various sensors. We use a distance sensor to detect obstacles, a gyroscope to measure rotation and direction, and a USB camera for visual input and image processing. The robot also has an L298N motor driver to control the movement of the wheels. All these parts work together to help the robot navigate, make decisions, and respond to challenges in real time.

4) 1) Software:
4) 1.1) Python Language:

We chose Python as the main programming language for our WRO robot because it is simple, powerful, and widely used in robotics and computer vision. Python allows us to write clear and organized code, making it easier to test, debug, and improve our program One of the main reasons we selected Python is its strong support for the OpenCV library, which we used to process images and recognize objects or patterns. OpenCV gave us the ability to detect lines, colors, and QR codes — features that were essential for our robot’s mission. Python also works perfectly with Raspberry Pi, which we used as the main controller. Its flexibility allowed us to easily connect sensors and motors, and integrate the results from OpenCV to make real-time decisions.

Using Python helped us focus on problem-solving and teamwork, since the language
is easy to understand and modify. Overall, Python and OpenCV together provided a powerful combination that made our robot more intelligent and efficient during the WRO challenge.

Python is used in our project because it is easy to learn and helps us control the robot accurately. With Python, we can program the robot’s movements, read sensor data, and analyze images from the camera. It also supports powerful libraries like OpenCV, NumPy, and more, which help us complete tasks quickly and efficiently during the competition challenges.

4.1.2) The Libraries:

RPi.GPIO Library:

The RPi.GPIO library is specifically designed to interact directly with the physical world through the general-purpose input/output pins on the Raspberry Pi. Imported here as GPIO, its primary function is to manage the flow of digital signals. You use it to set a pin as an output to send a High (1) or Low (0) signal, which controls devices like LEDs, motors, and actuators (turning them ON or OFF). Conversely, you can set a pin as an input to read the state of physical components, such as checking whether a button has been pressed or if a sensor has detected an object. This library is the foundational layer for low-level hardware control.

OpenCV Library:

OpenCV is a powerful and widely used library for computer vision tasks. In our WRO project, we use OpenCV to help the robot understand its surroundings through camera input. It allows the robot to detect colors, follow lines, and recognize objects or obstacles. OpenCV works well with Python and provides many ready-to-use functions that make image processing faster and easier. This helps improve the robot’s accuracy and responsiveness during competition challenges.

time Library:

The time library is a standard module built into Python that provides essential functions for managing time within a program. It is crucial for hardware projects, as physical devices often require specific timing to operate correctly. Its most common function is time.sleep(X), which pauses the execution of the program for a specified number of seconds (X). This delay is vital for tasks like creating rhythmic flashing patterns, allowing mechanical components time to move into position, or stabilizing sensor readings before processing them. It also offers functions for measuring time intervals and retrieving the current time .

Smbus Library:

The smbus library serves as a software interface for communicating with external devices using the I²C (Inter-Integrated Circuit) protocol, which is a very common serial communication method in embedded systems. I²C allows multiple devices, such as sophisticated sensors, memory chips, and display drivers, to communicate with the Raspberry Pi using only two wires (SDA and SCL). By importing smbus, Python code gains the ability to address specific external chips and send commands (write operations) or receive complex data (read operations) from them. This is essential for integrating advanced components that require a dedicated communication bus rather than simple ON/OFF signals .

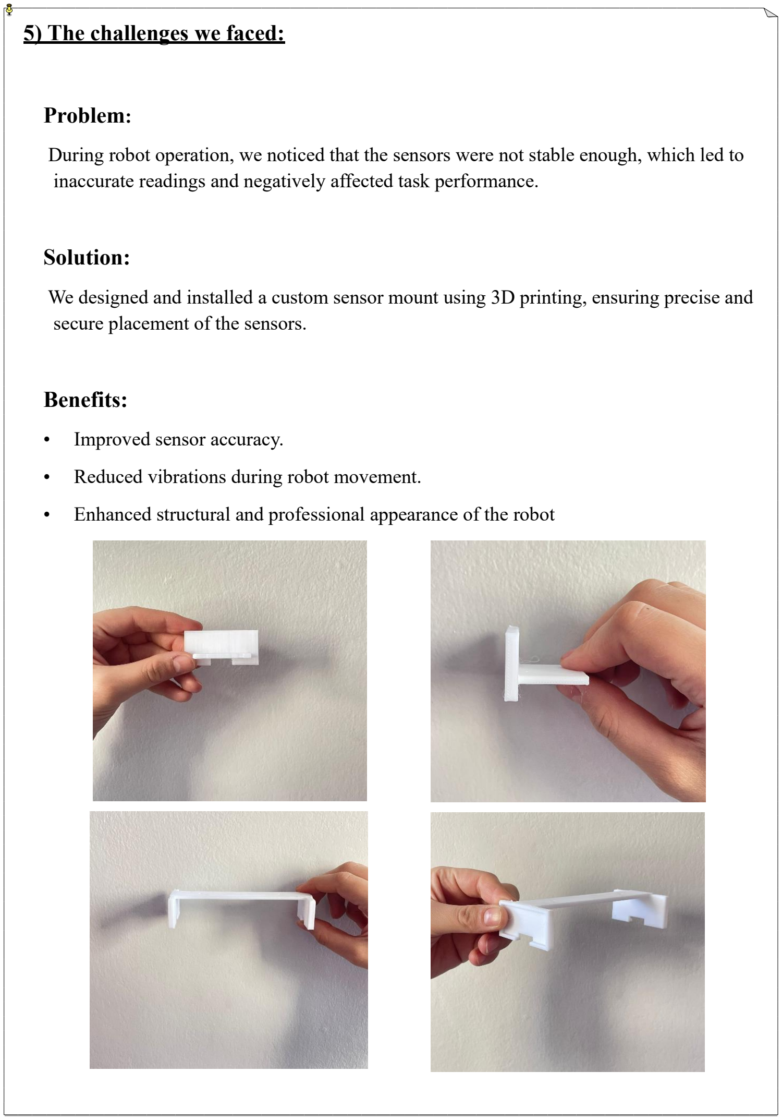
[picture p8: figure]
5) The challenges we faced:; Problem:; Solution:; secure placement of the sensors.; Benefits:; • Improved sensor accuracy.

During robot operation, we noticed that the sensors were not stable enough, which led to inaccurate readings and negatively affected task performance.

We designed and installed a custom sensor mount using 3D printing, ensuring precise and

- Reduced vibrations during robot movement.
- Enhanced structural and professional appearance of the robot

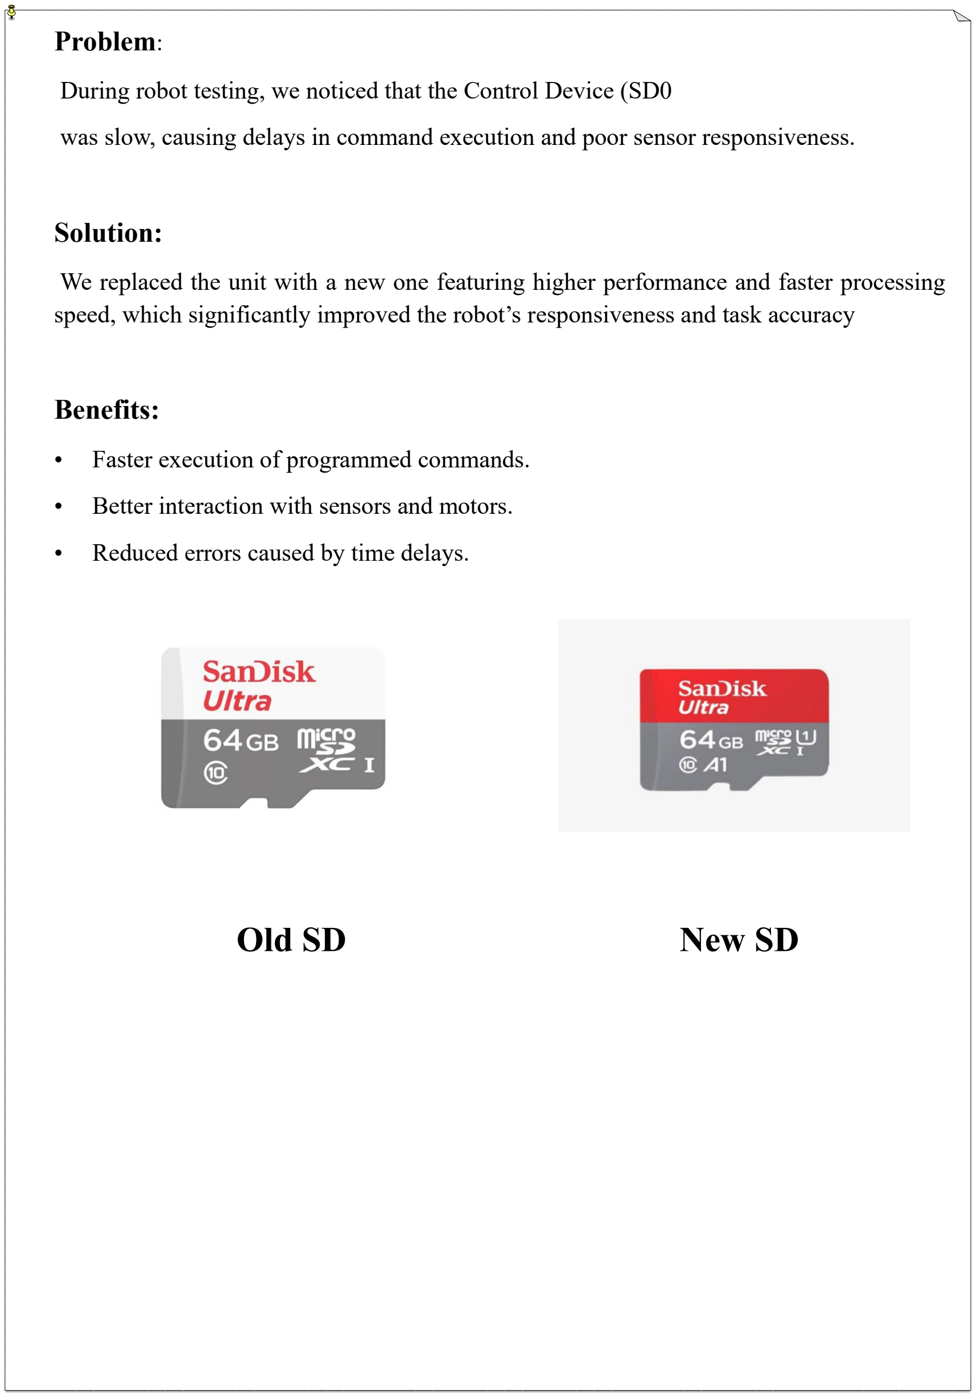
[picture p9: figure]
Problem:; Solution:; Benefits:; • Reduced errors caused by time delays.; Old SD; New SD

During robot testing, we noticed that the Control Device (SD0

was slow, causing delays in command execution and poor sensor responsiveness.

We replaced the unit with a new one featuring higher performance and faster processing speed, which significantly improved the robot’s responsiveness and task accuracy

- Faster execution of programmed commands.
- Better interaction with sensors and motors.

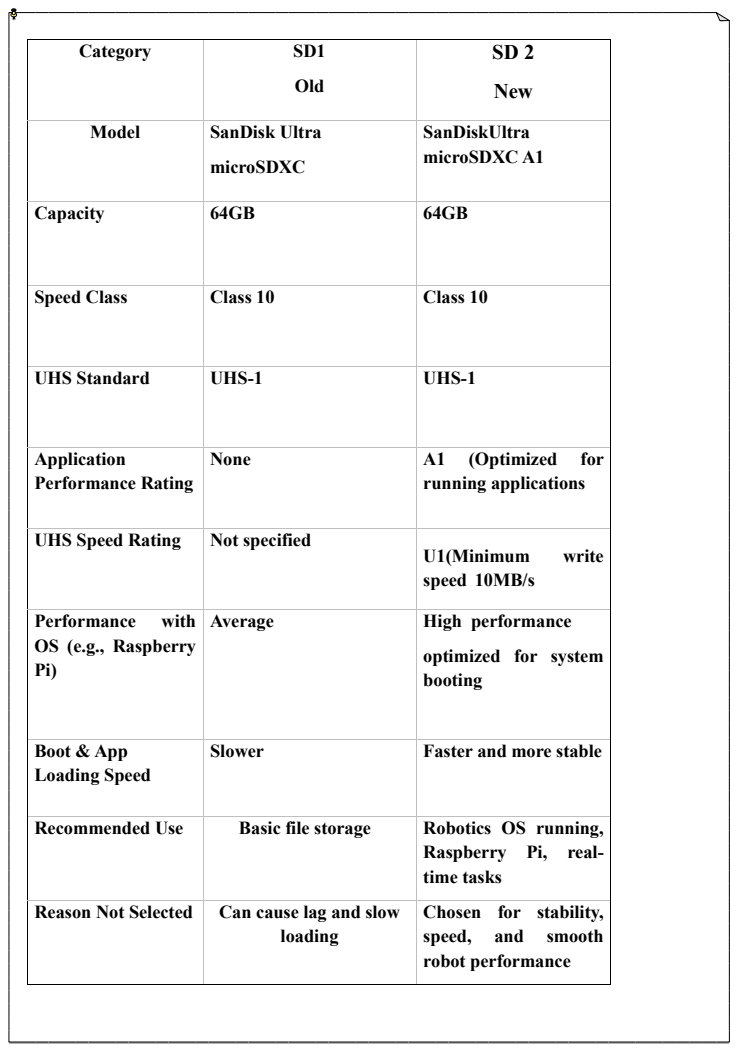
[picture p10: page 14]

Category | SD1 Old | SD 2 New

Model | SanDisk Ultra microSDXC | SanDiskUltra microSDXC A1

Capacity | 64GB | 64GB

Speed Class | Class 10 | Class 10

UHS Standard | UHS-1 | UHS-1

Application Performance Rating | None | A1 (Optimized for running applications

UHS Speed Rating | Not specified | U1(Minimum write speed 10MB/s

Performance with OS (e.g., Raspberry Pi) | Average | High performance optimized for system booting

Boot & App Loading Speed | Slower | Faster and more stable

Recommended Use | Basic file storage | Robotics OS running, Raspberry Pi, real-time tasks

Reason Not Selected | Can cause lag and slow loading | Chosen for stability, speed, and smooth robot performance

Problem:

While using the Raspberry Pi 4, we encountered several issues, including slow performance and unexpected system freezes. These problems affected the overall efficiency and reliability of our setup.

Solution:

To overcome these challenges, we upgraded our system to the Raspberry Pi 5, which offers improved processing power, better thermal management, and enhanced stability.

Benefits:

- Faster and more responsive performance
- Reduced system crashes and downtime
- Improved reliability and efficiency for continuous operation

Problem:

At the beginning, we used a camera because it provided good performance and accurate detection. However, after modifying the robot’s engineering design and adding the 3D funnel, the camera no longer fit properly. Its position affected the field of view, which reduced its efficiency and response accuracy during movement.

Solution:

We decided to replace the camera with New Camera that better match the updated design and work effectively with the new 3D funnel structure. This allowed us to maintain reliable environmental sensing without compromising the robot’s mechanical design or functionality.

Benefits:

With this change, the robot achieved better integration between the mechanical structure and the electronic components. The new Camera setup worked efficiently and provided a clear detection path, improving overall performance, stability, and reducing technical issues caused by unsuitable camera placement.

Old Camera | New Camera

Problem:

At the beginning of the project, we planned to use a color sensor to determine directions and guide the robot’s movement. However, we faced difficulties with color detection due to lighting changes and surface reflections in the competition environment. This affected the sensor’s accuracy and could cause the robot to make incorrect decisions.

Solution:

Instead of using the color sensor, we adopted a more reliable method by using the distance sensor. If the right sensor detects more than 160 cm, this means the robot should move counterclockwise. On the other hand, if the left sensor detects more than 160 cm, this means the robot should move clockwise. This approach allowed the robot to determine its direction accurately without relying on color detection.

Benefits:

This solution provided faster and more accurate direction control, making the robot less affected by lighting conditions or surface changes. It improved movement stability, enhanced performance, and increased reliability, helping the robot complete its path smoothly and efficiently.

Problem:

In the beginning, our robot relied only on the Ultrasonic sensor to determine its direction. However, we noticed that the robot sometimes drifted and did not stay perfectly on the intended path, especially when turning or moving for a long distance. This caused slight deviations that could affect its accuracy during the mission.

Solution:

To solve this issue, we added a gyroscope sensor alongside the distance sensor. The gyroscope helps the robot maintain a stable direction and corrects any drift by constantly monitoring the robot’s rotation angle. By combining both sensors, the robot can detect direction accurately and stay aligned with the path.

Benefits:

With the gyroscope added, the robot became more stable and precise in its movements. It no longer drifts easily, and its turns became smoother and more controlled. This upgrade improved the overall performance, reliability, and accuracy of the robot during the competition missions.

Problem:

After installing the camera on the robot, we noticed it wasn’t securely fixed, which caused vibrations during movement and reduced image accuracy.

Solution:

We designed a custom camera mount using 3D printing to ensure stable positioning and optimal viewing angle.

Benefits:

- Secure and stable camera installation.
- Improved image quality and visual processing.
- Easy adjustment of the camera angle when needed.

4) 2) Hardware:
4) 2.1) The robot chassis:

Firstly, the structure of the robot

This car is a self-assembled (DIY) model that is built on a metallic chassis and uses an Ackermann Steering system to simulate the motion of real cars.

The components of the car were connected and operated using a Raspberry Pi, programmed in Python to control movement and steering.

This is the chassis:

This car is not a remote-controlled vehicle; rather, it is an experimental platform developed to apply the principles of mechanics, control, and programming in the field of intelligent vehicles .

Thanks to the use of the Ackermann Steering system, the car replicates the actual steering mechanism of real vehicles, unlike the differential steering systems used in many traditional robots.

The car was entirely assembled and programmed manually as part of participation in the

The wheels of this smart robot car have specific material and performance characteristics :

Wheel Rims (Hubs): The rim material is ABS (Acrylonitrile Butadiene Styrene). They are purely aesthetic.

Tires (Rubber): The tire material is Rubber .

Performance: The rubber material provides a large coefficient of friction and strong grip (traction) force. This design is crucial for stable and controlled movement across different surfaces .

Internal Structure: All tires are internally fitted with a foam lining (insert). This foam insert provides necessary support and structure to the soft rubber tire, which is essential for consistent performance and shock absorption in RC and robot cars.

4) 2.2) Ackermann Steering:

This is the servo that controls the wheels using the Ackermann Steering system:

Ackermann Steering Geometry: Precision Path Management

The chassis design of our autonomous vehicle is fundamentally based on the Ackermann Steering Geometry. We implemented a custom-modified version of this linkage system to ensure optimal cornering performance .

1. Principle of Operation:

Unlike simpler steering methods (like skid steering), the Ackermann principle ensures that during a turn, the steering axis of all four wheels intersects at a single, momentary center point. This is achieved by ensuring the inner wheel (the wheel closer to the turn’s center) rotates at a sharper angle than the outer wheel.

This difference in rotation angle is critical because it forces the wheels to follow four distinct radii, allowing the inner wheel to travel a shorter path and the outer wheel a longer path, preventing any lateral slippage .

In our RWD system, the front wheels execute the steering motion around their respective pivots, while the single DC motor drives the non-steering rear wheels .

2. Mathematical Description (The Ideal Geometry):

This diagram illustrates the Ideal Ackerman

Steering Geometry. This geometry ensures
that all four wheels, when steered, trace concentric circles around a single, common point, the Ackerman Center (C_a) .

This fundamental relationship is governed by the vehicle's fixed dimensions—the Track Width (T) and the Wheelbase (W)—and the required steering angles :

cot(a_o) - cot(a_i) = T/W

Where a\_i is the inner wheel steering angle and a\_o is the outer wheel steering angle .

In this ideal setup :

The Inner Wheel Angle (a\_i) is always greater than the Outer Wheel Angle (a\_o) (a\_i > a\_o) .

The lines drawn perpendicular to the plane of each wheel intersect precisely at C_a, ensuring all wheels roll without excessive side-slip .

Note: Real-world steering systems use a Modified Ackerman principle to optimize performance across the entire steering range, deviating slightly from this ideal formula .

3 .Advantages for Our Robotic System :

Implementing the Ackermann geometry was a strategic choice that provided several specific benefits essential for the competition requirements :

Elimination of Tire Slippage:
The main advantage is the
prevention of tire scrubbing and
slippage, which is crucial for accurate path following and maintaining maximum traction on the carpet surface .

Precise Path Management: The system offers high control over the front wheel's angle, allowing for precise steering control necessary to navigate between colored obstacles and adhere to strict course boundaries .

Single-Motor Compliance: This configuration naturally supports the requirement of using only a single DC motor for propulsion, simplifying the mechanical drivetrain while maintaining high maneuverability.

4) 2.3) Robot mind: The Raspberry Pi 5 Single-Board Computer (SBC):

The Raspberry Pi 5 serves as the core computational brain of the robot, tasked with executing the Python-based control program, managing all peripherals, and performing computationally intensive tasks like Computer Vision and Sensor Fusion in real-time. The decision to utilize the Pi 5— a significant upgrade from its predecessors—is driven by its unparalleled performance uplift crucial for autonomous mobility.

- Performance and Processing Core :

The Pi 5 is architecturally superior, featuring a 2.4GHz quad-core Arm Cortex-A76 processor with 512KB per-core L2 caches and a 2MB shared L3 cache. This configuration delivers a 2 to 3 times increase in CPU performance relative to the Pi 4, which is paramount for ensuring low-latency decision-making and the fast execution of complex path-planning algorithms .

Graphics processing is managed by the 800MHz Video Core VII GPU, offering a substantial uplift in graphics performance and supporting modern APIs like Vulkan 1.2. This hardware acceleration is vital for speeding up OpenCV operations and overall image processing, which directly translates to faster detection and response times for our Computer Vision system (e.g., traffic light recognition) .

Furthermore, the availability of high-speed LPDDR4X-4267 SDRAM (with options up to 16GB) provides the necessary memory bandwidth and capacity to manage large data streams from the USB camera and support memory-intensive Sensor Fusion algorithms effectively.

- Enhanced I/O and Peripheral Connectivity :
The Pi 5’s revolutionary RP1 "southbridge" chip provides a major step change in peripheral performance, directly addressing critical bottlenecks for robotics applications :
- USB Bandwidth:
The two USB 3.0 ports now support simultaneous 5Gbps operation. This is critical for connecting our high-speed USB camera, guaranteeing a high, consistent frame rate vital for real-time traffic light detection and line following without data latency issues .
- Camera Interfaces:
The platform replaces the single CSI interface with a pair of 4-lane 1.5Gbps MIPI transceivers, effectively tripling the total camera bandwidth. This significantly improves the processing capability for the vision system and provides a robust future pathway for integrating dedicated CSI-2 modules or stereoscopic vision systems .

- Low-Level Control:
The standard 40-pin GPIO header remains the primary interface for all low-level communication. This includes PWM signals to the motor driver and servo, and reliable serial buses (I2C and SPI) for data exchange with the MPU-6050 IMU and the Encoder .
- Power Management and Reliability:
The Raspberry Pi 5 requires a dedicated 5V/5A DC power input. To meet this demand from the robot's 9V battery, the LM2596 Voltage Regulator is essential for stepping down the input voltage to the stable 5V rail. This ensures the Pi 5 operates reliably, utilizing its Real-Time Clock (RTC) and on-chip oscillator for precise timing across all autonomous operations, which activates the main Python script.

4) 2.4.1) Motor Driver L298N:

L298N Dual H-Bridge Motor Driver: The Power Bridge The L298N module serves as an essential protective and intermediary power stage between the robot's battery and its drive motor. The Necessity of a Driver: The Raspberry Pi 5 (our main controller) operates using low-power signals and cannot safely source or sink the high current required by the DC propulsion motor. Attempting to connect the high-power battery circuit directly to the Pi's low-voltage GPIO pins would result in immediate and irreversible damage to the controller. Therefore, the primary role of the L298N is to act as a current amplifier and insulator, safely handling the large electrical load demanded by the motor. How the System Works (The Dam Analogy): The L298N can be visualized as a large, reinforced concrete dam built to manage the powerful current flowing from the 9V battery (the reservoir) to the motor (the turbine). The Raspberry Pi acts as the control mechanism that precisely regulates the dam's sluice gates (via PWM signals). The Pi merely sends low-voltage commands to the L298N, instructing when and how much of the high-power battery current should be directed to the motor, without ever having to handle the power itself. Component Description: This module is based on the widely used L298 Dual H-Bridge Integrated Circuit. While the board is capable of controlling two DC motors independently (up to 2A peak current each), our application utilizes only one motor port to drive our single-motor RWD system. The unit is optimized for microcontroller interfacing, requiring only a few digital lines for full control. The board also features essential integrated components, including LED power indicators, internal protection diodes, and an onboard +5V voltage regulator which can supply power to the low-voltage controller (like the Raspberry Pi) for convenience. Key Technical Data :

4) 2.4.2) Driver: L298N Dual H-Bridge DC Motor Driver

Operating Voltage Range: DC 5 V - 35 V
(Motor Power)

Peak Current: 2 Amp per motor

Input Logic Voltage (Control Signal) :

Low: -0.3 ≤ Vin ≤ 1.5V (control signal is invalid) .

High: 2.3V ≤ Vin ≤ Vss (control signal active).

Maximum Power Dissipation: \text{20W} (at
T = 75^\circ C)

On-board Feature: Integrated +5V regulated output supply .

Approximate Dimensions: 4.3cm × 4.3cm × 2.7cm

4) 2.5) Motor DC:

This motor belongs to the class of DC Geared Motors, specifically the JGA25-370 series, known for providing a necessary trade-off between speed and torque for robotics and automation applications. It is designed to be highly compatible with popular microcontroller platforms such as Arduino, Raspberry Pi, and STM32, utilizing common DC motor driver modules.

- Model Name and Type: JGA25-370 DC Gear Motor. The name implies a 25mm gearbox diameter attached to a 370 series motor .
- Operating Voltage: The nominal operating voltage is 12V DC.
- Output Speed (No-load): It provides an output speed of 210RPM (Revolutions Per Minute) under no-load conditions .
- Torque Capability: The motor delivers up to 12Kg • cm of torque. This makes it suitable for medium-load mechanical motion control projects .
- Gearbox Material: It features a durable all-metal gearbox for enhanced strength and long service life, ensuring stable and reliable continuous operation .
- Output Shaft: The typical output shaft diameter is 6mm .
- Typical Applications: This motor is ideal for building robots, conveyor systems, smart vehicles, and other DIY projects requiring controlled motion .
- Stall Current: The internal motor (before the gearbox) can draw a Stall Current (maximum current draw when the shaft is blocked) of approximately 2.2 Amps at 12V .
- Motor Driver Requirement: This means the chosen motor driver (the module linking the motor to the Raspberry Pi) must have a continuous current rating exceeding 2.2 Amps per channel to safely operate the motor, especially when the car is starting or pushing against an obstacle .

4) 2.6) Servo Motor:

Precise Steering Actuator the Servo Motor is the critical actuator responsible for translating the path-planning commands from the Raspberry Pi into physical steering motion Integration with Ackermann Geometry Function: The servo is connected via a custom linkage to the front wheels, enabling the precise, differential steering angles required by the Ackermann Steering Geometry. Model: Based on its characteristics (and likely MG996R designation), the model used is a Digital, High-Torque Servo with Metal Gears. The high torque rating10 ~( kg٠ cm )ensures sufficient force to overcome the mechanical friction and maintain the steering angle under load .

Control and Power Control Protocol: The servo angle is precisely controlled by sending Pulse Width Modulation (PWM) signals from the Raspberry Pi's GPIO header. The duration of the pulse dictates the angular position of the angular position of the wheel. Power: The servo requires a stable operating voltage typically in the 5V - 6V range. This power is reliably supplied by the Step-down Module (Voltage Regulator), ensuring steady operation independent of the main 9V battery fluctuations.

4) 2.7) Voltage regulator XL4015:

The DC-DC Step-down Module is a non-isolated buck converter based on the widely used LM2596 integrated circuit. It serves as a crucial power conditioning component, managing the transition from the high-power drive system to the sensitive control electronics .

Power Regulation Necessity The robot's propulsion system operates on a 9V battery supply, necessary for the DC drive motor. However, the sensitive low-voltage components— namely the Raspberry Pi 4 5V/3A minimum), the Servo Motor, and all digital Sensors— require a stable and lower operating voltage. The primary function of this module is to safely and efficiently step-down the 9V input voltage to a regulated 5V output. This prevents potential damage to the control board and ensures power stability, which is vital for the reliable operation of the Raspberry Pi's CPU and GPIO communications .

Key Operational Data The module accepts a wide input range 4.5V to 40V), easily accommodating the 12V battery output. It is manually tuned to provide a precise 5V output voltage and is rated for a continuous output current of approximately 3A, providing a sufficient power budget for all low-power electronics in the system. The high conversion efficiency (> 80%) minimizes energy loss as heat, preserving battery life.

4) 2.8.1) Gyroscope MPU6050:

Inertial Measurement Unit (IMU): MPU-6050 The MPU-6050 Inertial Measurement Unit (IMU) serves as the primary sensor for motion and orientation tracking, correcting for mechanical and environmental inaccuracies that cannot be managed by vision or distance sensors .

Function and Integrated Components The MPU-6050 is a sophisticated MotionTracking device that integrates a 3-axis gyroscope and a 3-axis accelerometer. It utilizes 16-bit Analog-to-Digital Converters (ADCs) for high-precision data capture .

Gyroscope (Angular Rate): Measures the rate of rotation around the X, Y, and Z axes. This is essential for detecting unwanted yaw (heading deviation) and precisely correcting the Ackermann steering angle. The range is user-programmable up to +- 2000⁰/sec .

Accelerometer (Linear Acceleration): Measures linear acceleration and gravity, used to determine the robot's tilt angle (roll and pitch) and estimate linear distance traveled. The range is programmable up to +-16g .

Digital Motion Processor (DMP): This integrated hardware unit processes complex 6-axis Motionfusion algorithms. Crucially, the DMP offloads computation from the Raspberry Pi by processing raw sensor data into clean, ready-to-use orientation information directly on the chip .

System Integration and Power The MPU-6050 communicates with the Raspberry Pi 4 using the efficient I2C serial communication protocol. This protocol is highly efficient, requiring a minimum number of dedicated GPIO pins .

Power: The module operates between
3V to 5V and is safely powered by the
5V} regulated output from the LM2596
module. Role in Navigation the IMU provides the core data for internal navigation (dead reckoning). Regardless of whether the system implements explicit sensor fusion with the ultrasonic sensors, the highly accurate angular rate and acceleration data are crucial for stabilizing the robot's movement and ensuring that the programmed path is maintained against physical disturbances.

4) 2.8.2) Gyroscope Working Principle:

A gyroscope is a sensor used to measure the rate of rotation around the different axes of an object, allowing it to detect how the body rotates in space. Gyroscopes usually work by measuring the Coriolis force acting on a moving element inside the sensor and converting it into an electrical signal. (Note: Coriolis force is an apparent force that arises when an object moves in a rotating frame of reference.) This signal enables the calculation of the change in angle over time, allowing robots to know their orientation accurately, maintain balance, or move in a straight line. Gyroscopes are widely used in robotics for navigation and motion control

Equation

θ = ∫ ω dt

Symbols Explanation:

Angle rotated (degrees or radians). : θ

Rotation rate (degrees/s or rad/s). : ω

Time interval between gyroscope readings (seconds (: dt

- Role of the Gyroscope:

In our robot, the gyroscope helps determine the robot's orientation precisely when facing turns and obstacles. In the Obstacle Challenge, it measures the robot's rotation rate and calculates the change in angle to decide whether to turn left or right, keeping it aligned with the path. In the Open Challenge, the gyroscope works alongside distance sensors to avoid collisions, maintain a fixed distance (~20 cm) from walls or obstacles, and allow the robot to make smart turning decisions without relying solely on the path lines

4) 2.9.1) Ultrasonic In our robot:

Ultrasonic Sensors (HC-SR04): Comprehensive ToF Ranging System The robot is equipped with a total of four HC-SR04 Ultrasonic Sensors that form the primary short-range ranging system. These sensors provide the vehicle with echolocation capabilities, on par with how bats and dolphins locate objects in complete darkness and beneath the water surface. This array is fundamental for robust, real-time obstacle avoidance and precise navigation along the course boundaries. Strategic Implementation and System Integration The four HC-SR04 sensors are strategically positioned to maximize situational awareness: one mounted in the front, one in the rear, and one on each of the right and left sides of the chassis. This arrangement minimizes blind spots and provides the angular data necessary for advanced Sensor Fusion. Power and Interface: The sensors require a stable +5V regulated supply, drawing less than 15mA each. Each sensor utilizes two dedicated GPIO pin (Trigger and Echo) on the Raspberry Pi for control and data acquisition. Sensor Fusion Role: The simultaneous input from four points allows the control system to accurately determine both the distance and the angular position of an obstacle. This redundancy is vital for high-reliability autonomy, allowing the algorithm to differentiate between a critical frontal obstacle and a simple boundary wall alongside the vehicle .

Principle of Operation and Technical Specification The HC-SR04 module operates on the principle of measuring the Time-of-Flight (ToF) of an ultrasonic sound wave. 1–Triggering: Measurement begins when the Raspberry Pi sends a minimum 10uS high pulse to the Trigger pin, prompting the transmitter to emit an 8-cycle burst of ultrasonic sound at 40kHz. 2– Echo Reception: The sound wave reflects off an object, and the duration it takes to return is measured. The sensor outputs a high pulse on the Echo pin, the width of which is directly proportional to the distance. 3– Calculation: The Raspberry Pi measures this pulse width (time), and the distance is calculated using the formula Distance = Speed × Time, divided by two since the time measured is for the signal's round trip. The sensor boasts a practical measuring range of 2cm to 400cm and an accuracy that can reach 3mm. This combination of range and precision makes it perfectly suited for the short-range, dynamic obstacle avoidance challenges presented in the competition course.

4) 2.9.2) Ultrasonic Sensor Working Principle:

The ultrasonic sensor measures distance by emitting high-frequency sound waves that are beyond human hearing, typically above 20 kHz, and detecting the echo that bounces back from an object. The sensor consists of a transmitter that sends ultrasonic waves and a receiver that listens for the reflected echo. When the transmitter emits a short burst of sound waves, they travel through the air, hit an object, and return to the sensor as an echo

When the transmitter emits a short burst of sound waves, they travel through the air, hit an object, and return to the sensor as an echo. The sensor calculates the distance by measuring the time interval between sending the wave and receiving the echo, using the formula:

Distance = (Speed × Time) / 2

Dividing by two accounts for the round trip
of the waves. The speed of sound is approximately 343 meters per second at room temperature, and it can vary with environmental conditions such as temperature and humidity, Ultrasonic sensors are typically accurate within ±3 millimeters and can measure distances ranging from 2 centimeters
to 400 centimeters. They usually have a
detection angle of 15 to 30 degrees, so objects
outside this range may not be detected. These sensors are widely used in robotics for obstacle detection, in cars as parking sensors, in measuring liquid levels, and in various industrial automation applications

- Role of the Distance Sensor:

To navigate the initial stage intelligently, we developed a dedicated algorithm that empowered the robot to make autonomous directional decisions, Prior to encountering the first turn, the robot was in a state of uncertainty, unsure whether to proceed clockwise or counterclockwise.

We incorporated ultrasonic sensors into the robot’s design to provide it with continuous spatial awareness. These sensors measured the distance to nearby obstacles on both the left and right sides.

Right Sensor: Conversely, if the right sensor measured a distance beyond 160 cm, the robot opted to move counterclockwise

Left Sensor: If the left ultrasonic sensor detected a distance exceeding 160 cm (indicating ample space on that side), the robot interpreted this as a signal to move clockwise

Figure 3: the robot moved on the game field counterclockwise

Figure 4: the robot moved on the game field with clockwise

Moreover, while traveling in a straight path the robot maintained a safety buffer of 20cm from the inner wall. If this distance was breached, the system automatically adjusted the trajectory to keep the robot stable and balanced This algorithm allowed the robot to dynamically adapt to its surroundings, making intelligent path choices and real-time corrections, embodying a sense of spatial awareness similar to advanced autonomous systems

Figure 5: Start counterclockwise Figure 6: Start with clockwise

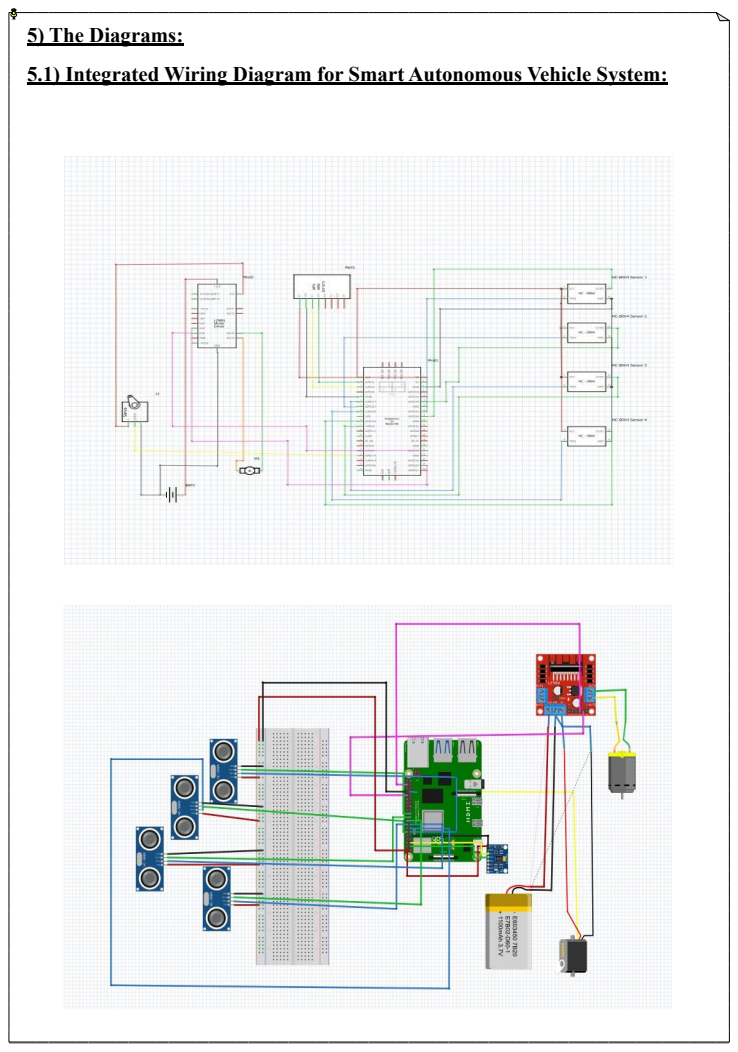
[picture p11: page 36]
5) The Diagrams:

5.1) Integrated Wiring Diagram for Smart Autonomous Vehicle System:

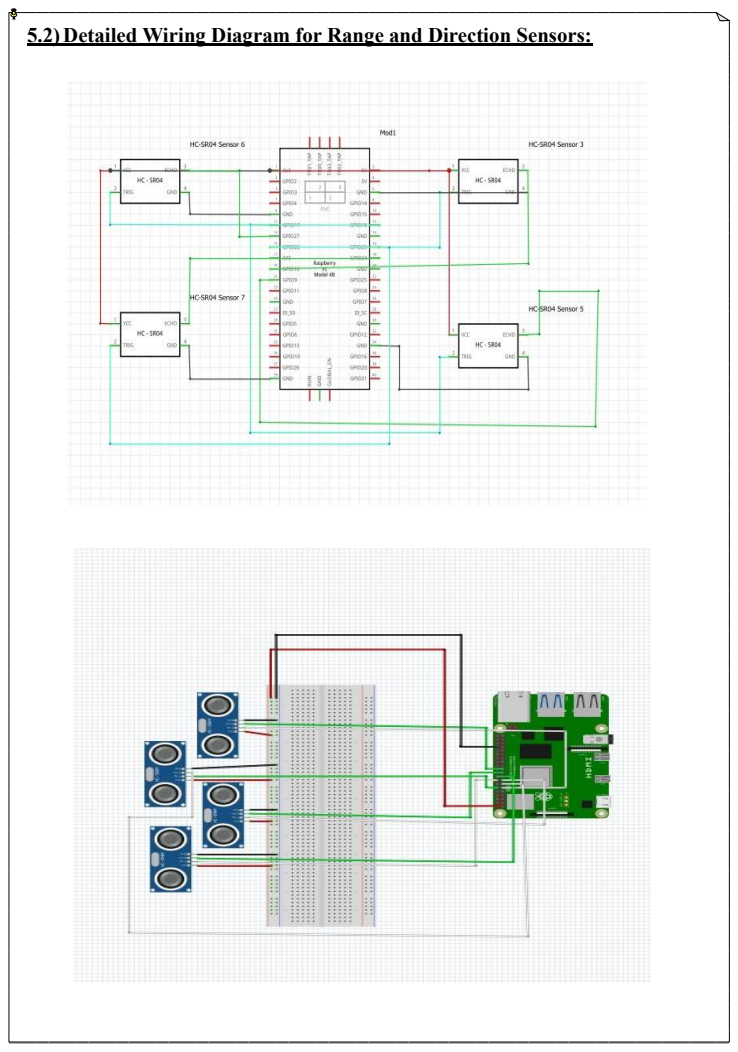
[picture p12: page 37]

5.2) Detailed Wiring Diagram for Range and Direction Sensors:

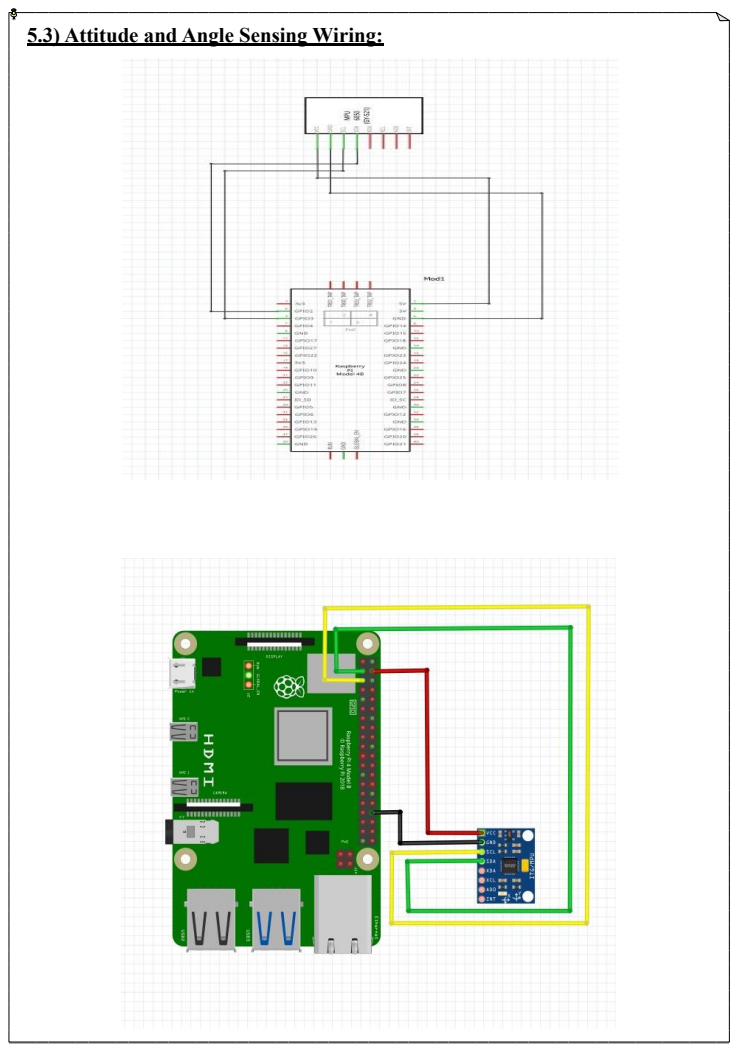
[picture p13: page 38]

5.3) Attitude and Angle Sensing Wiring:

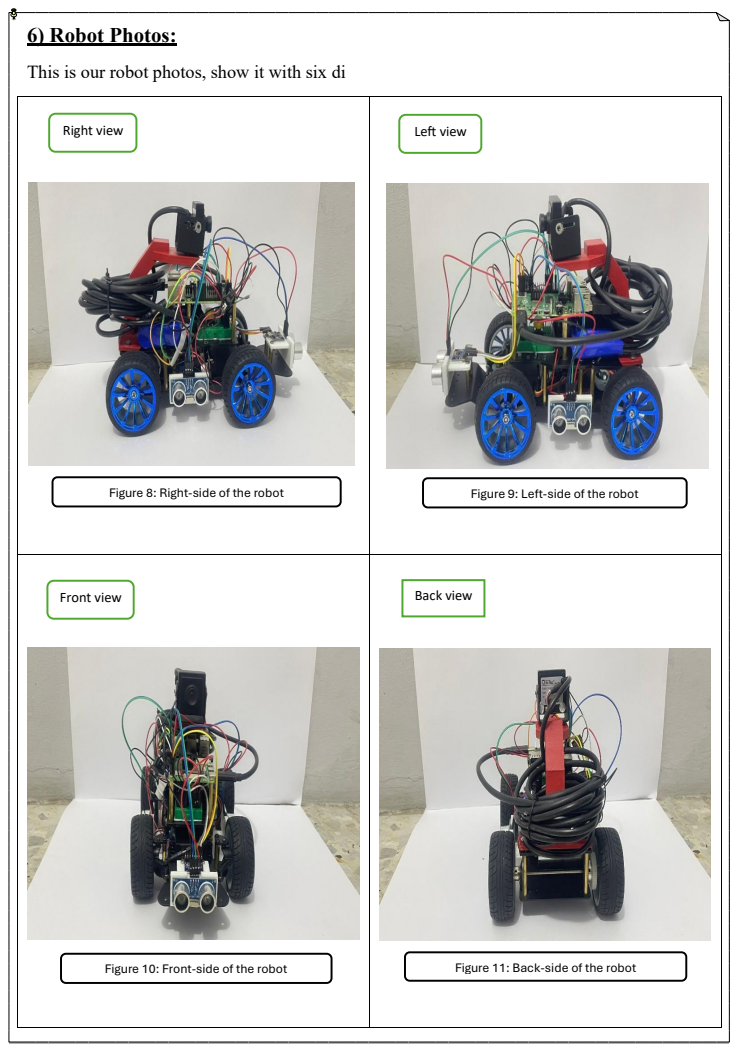
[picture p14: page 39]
6) Robot Photos:; Right view; Left view; Front view; Back view; Figure 8: Right-side of the robot; Figure 9: Left-side of the robot; Figure 10: Front-side of the robot; Figure 11: Back-side of the robot

This is our robot photos, show it with six di

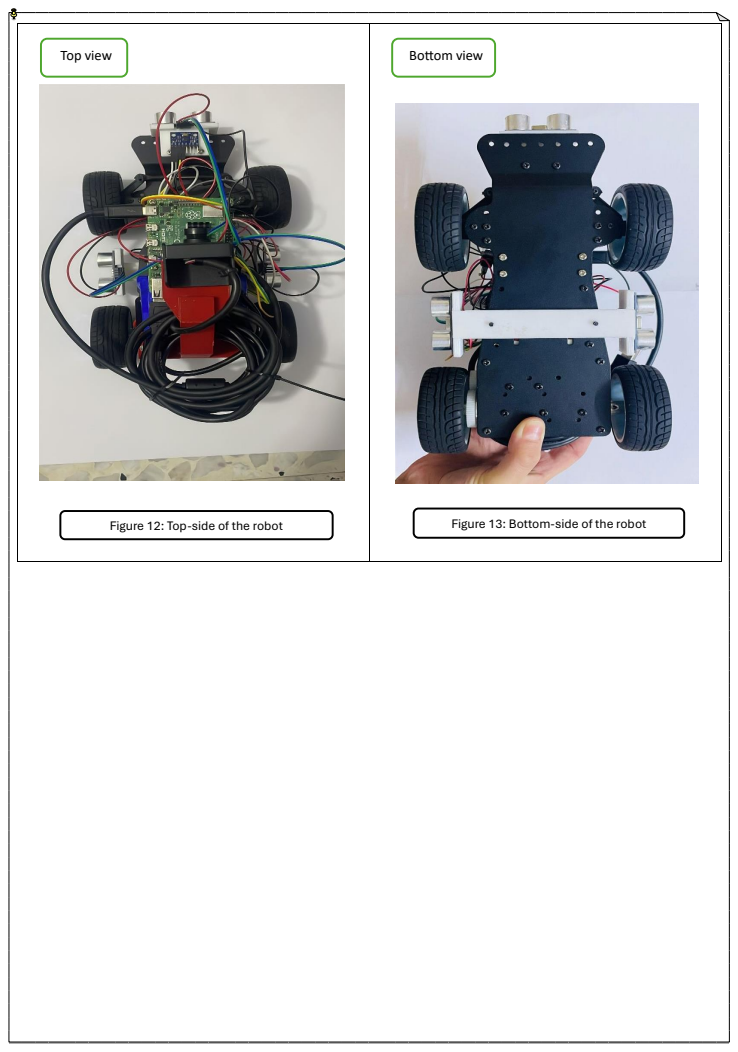
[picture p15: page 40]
Top view; Figure 12: Top-side of the robot; Figure 13: Bottom-side of the robot; Bottom view

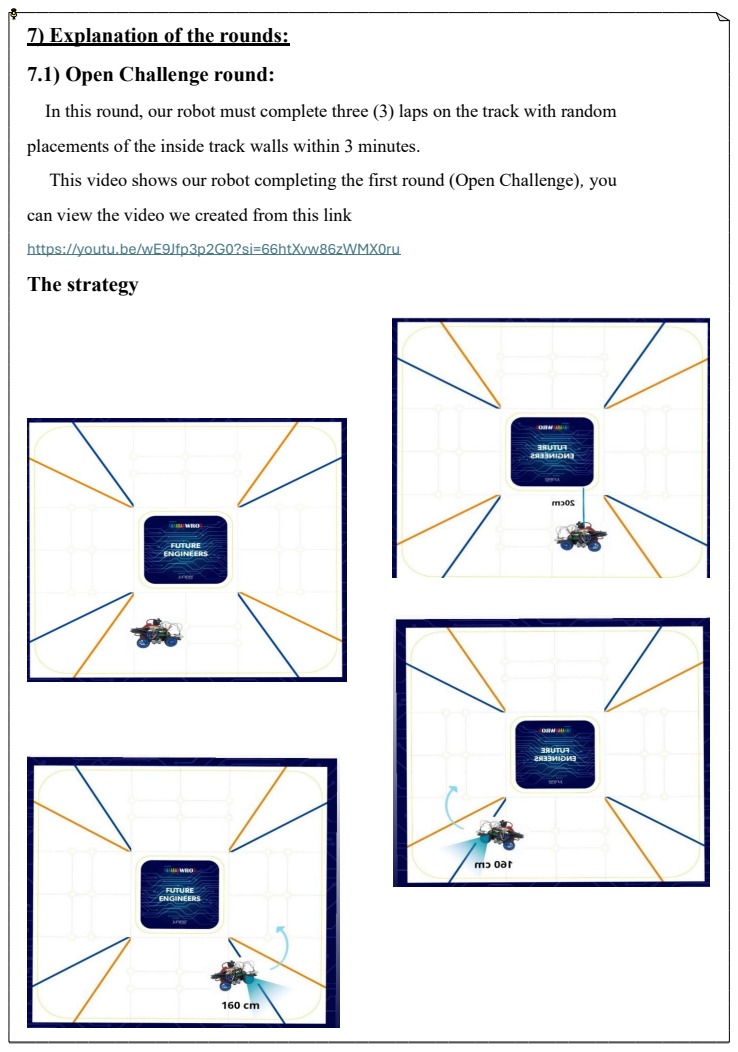
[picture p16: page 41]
The strategy

7) Explanation of the rounds:

7.1) Open Challenge round:

In this round, our robot must complete three (3) laps on the track with random

placements of the inside track walls within 3 minutes.

This video shows our robot completing the first round (Open Challenge), you

can view the video we created from this link
https://youtu.be/wE9Jfp3p2G0?si=66htXvw86zWMX0ru

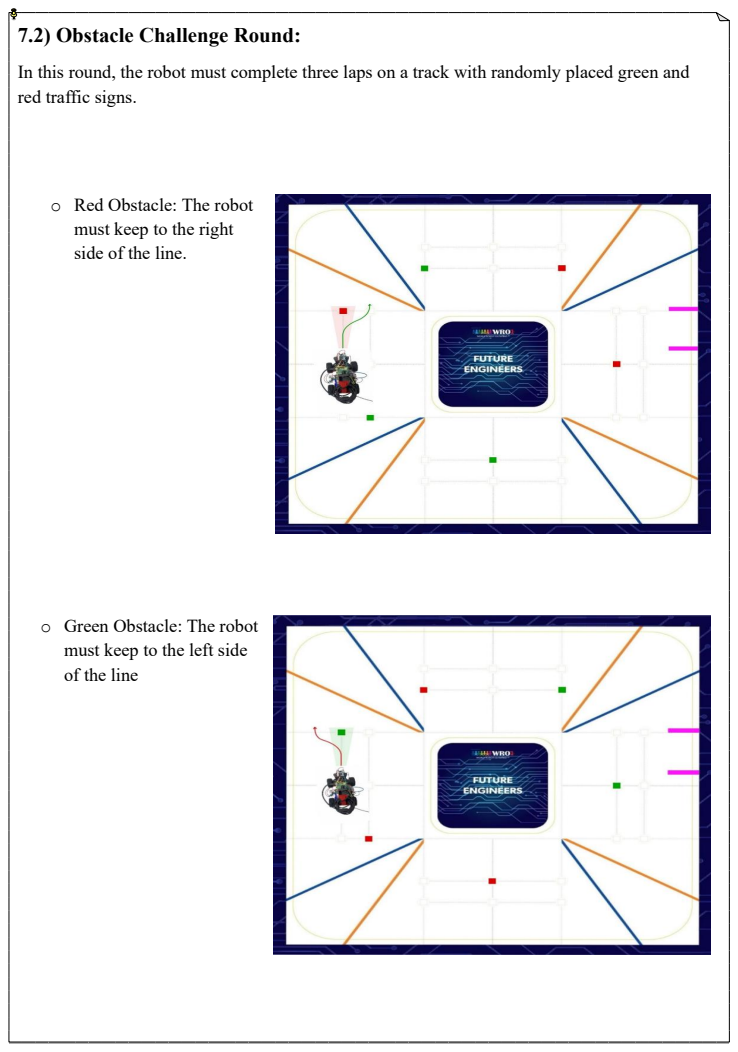
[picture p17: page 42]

7.2) Obstacle Challenge Round:

In this round, the robot must complete three laps on a track with randomly placed green and
red traffic signs.

• Red Obstacle: The robot
must keep to the right
side of the line.

• Green Obstacle: The robot
must keep to the left side
of the line

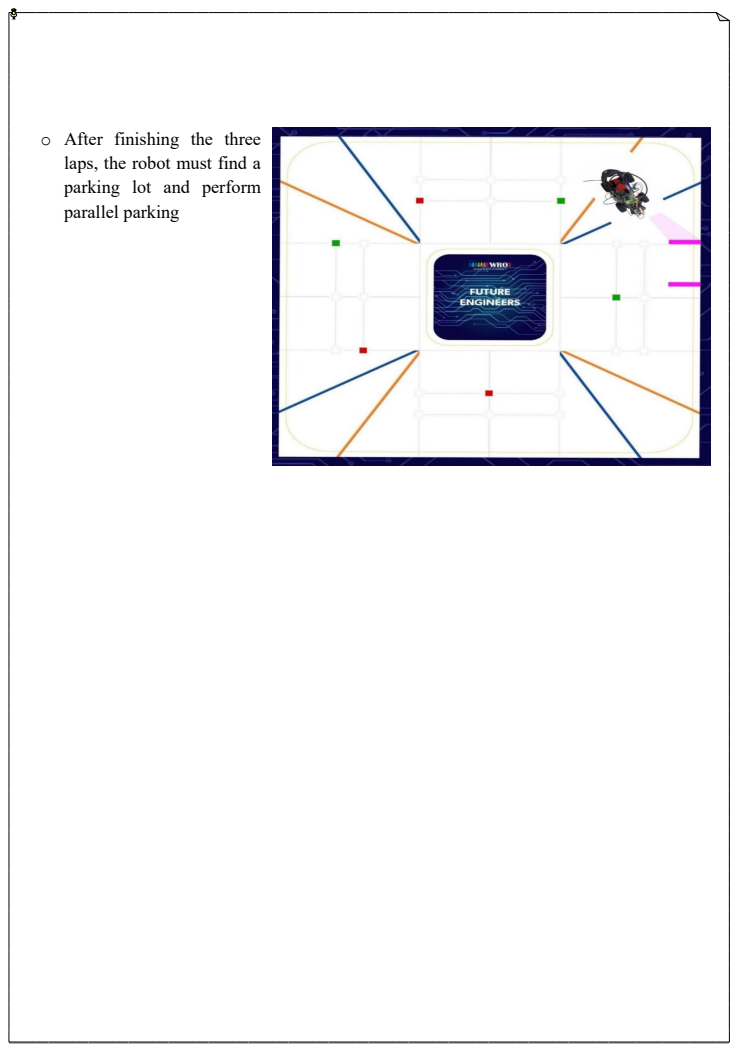
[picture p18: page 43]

• After finishing the three
laps, the robot must find a
parking lot and perform
parallel parking

8.1) Flowchart [Open Challenge round]:

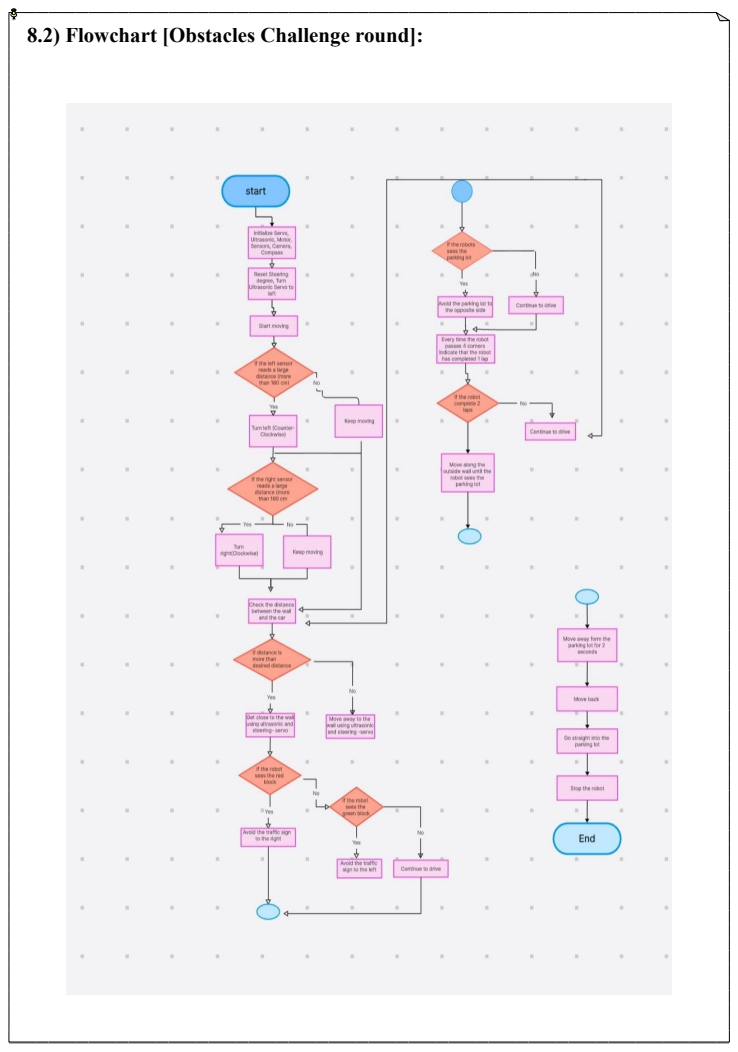
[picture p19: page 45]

8.2) Flowchart [Obstacles Challenge round]:

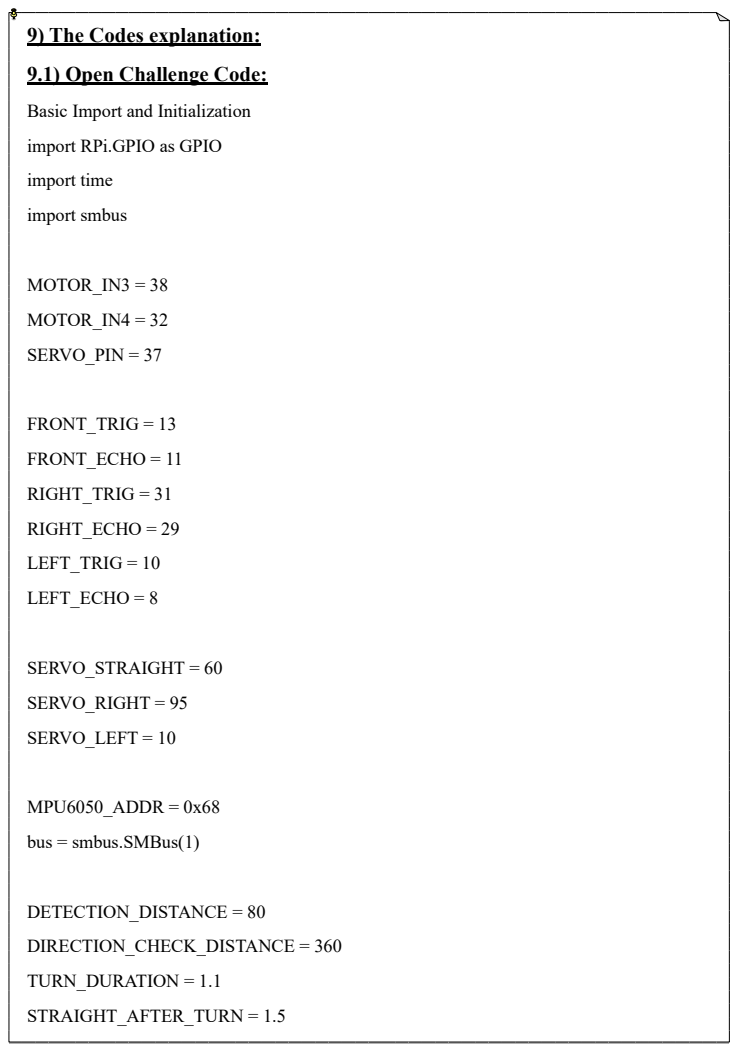
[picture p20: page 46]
import time; import smbus; MOTOR_IN3 = 38; MOTOR_IN4 = 32; SERVO_PIN = 37; FRONT_TRIG = 13; FRONT_ECHO = 11; RIGHT_TRIG = 31; RIGHT_ECHO = 29; LEFT_TRIG = 10; LEFT_ECHO = 8; SERVO_STRAIGHT = 60; SERVO_RIGHT = 95; SERVO_LEFT = 10; MPU6050_ADDR = 0x68; DETECTION_DISTANCE = 80; DIRECTION_CHECK_DISTANCE = 360; TURN_DURATION = 1.1; STRAIGHT_AFTER_TURN = 1.5

9) The Codes explanation:

9.1) Open Challenge Code:

Basic Import and Initialization

import RPi.GPIO as GPIO

bus = smbus.SMBus )1 (

Importing the basic libraries to control the robot, defining the ports connected to the Raspberry Pi for each component, setting the three servo angles, and defining the distances that constitute a close obstacle requiring the robot to stop and detect the path direction (clockwise or counter-clockwise).

Initialization GPIO Initialization mpu6050 Initialization ultrasonic

def setup_gpio():

GPIO.setmode(GPIO.BOARD)

GPIO.setwarnings(False)

GPIO.setup(MOTOR_IN3, GPIO.OUT)

GPIO.setup(MOTOR_IN4, GPIO.OUT)

GPIO.setup(SERVO_PIN, GPIO.OUT)

for trig in [FRONT_TRIG, RIGHT_TRIG, LEFT_TRIG]:

GPIO.setup(trig, GPIO.OUT)

GPIO.output(trig, False)

for echo in [FRONT_ECHO, RIGHT_ECHO, LEFT_ECHO] :

GPIO.setup(echo, GPIO.IN)

def mpu6050_init():

try :

bus.write_byte_data(MPU6050_ADDR, 0x6B, 0)

time.sleep )0.1(

return True

except :

return False

Motor Control [The motor runs, stops]

GPIO.output(MOTOR_IN3, GPIO.LOW)

GPIO.output(MOTOR_IN4, GPIO.HIGH)

GPIO.output(MOTOR_IN4, GPIO.LOW)

Controlling the servo, preparing it, and setting it to a specific angle.

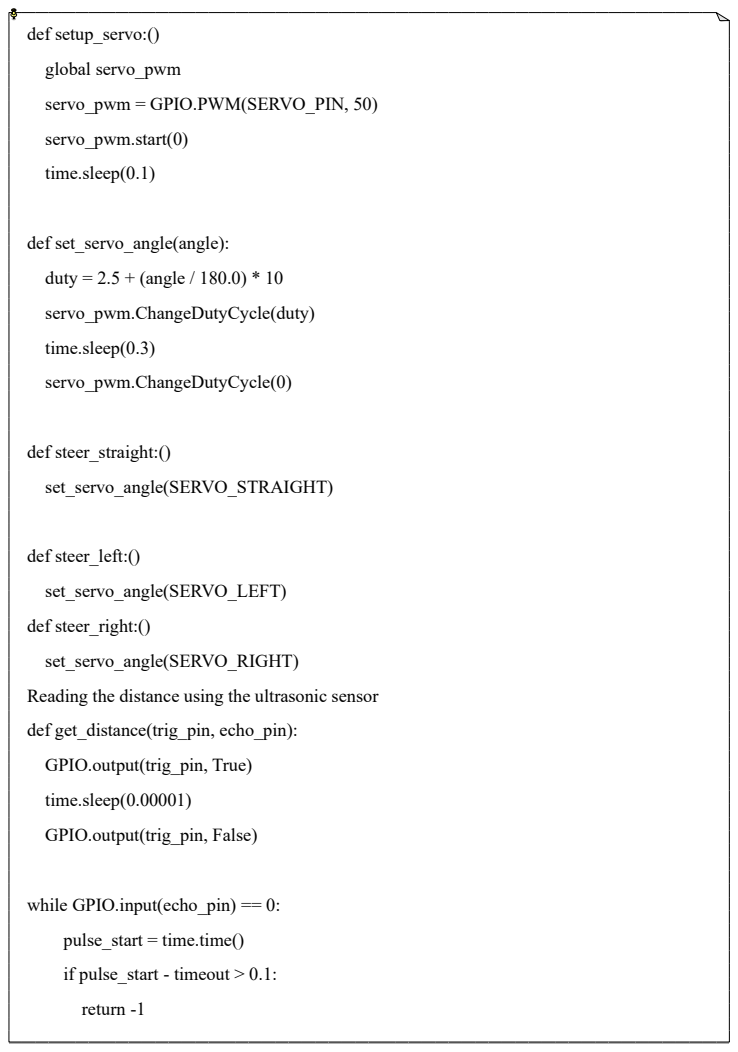
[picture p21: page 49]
def setup_servo :)(; global servo_pwm; servo_pwm = GPIO.PWM(SERVO_PIN, 50); servo_pwm.start)0 (; time.sleep )0.1 (; def set_servo_angle(angle) :; duty = 2.5 + (angle / 180.0) * 10; servo_pwm.ChangeDutyCycle(duty); time.sleep )0.3 (; servo_pwm.ChangeDutyCycle )0 (; def steer_straight :)(; set_servo_angle(SERVO_STRAIGHT); def steer_left :)(; set_servo_angle(SERVO_LEFT); def steer_right :)(; set_servo_angle(SERVO_RIGHT); def get_distance(trig_pin, echo_pin) :; time.sleep)0.00001 (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

Reading the distance using the ultrasonic sensor

GPIO.output(trig_pin, True)

GPIO.output(trig_pin, False)

while GPIO.input(echo_pin) == 0 :

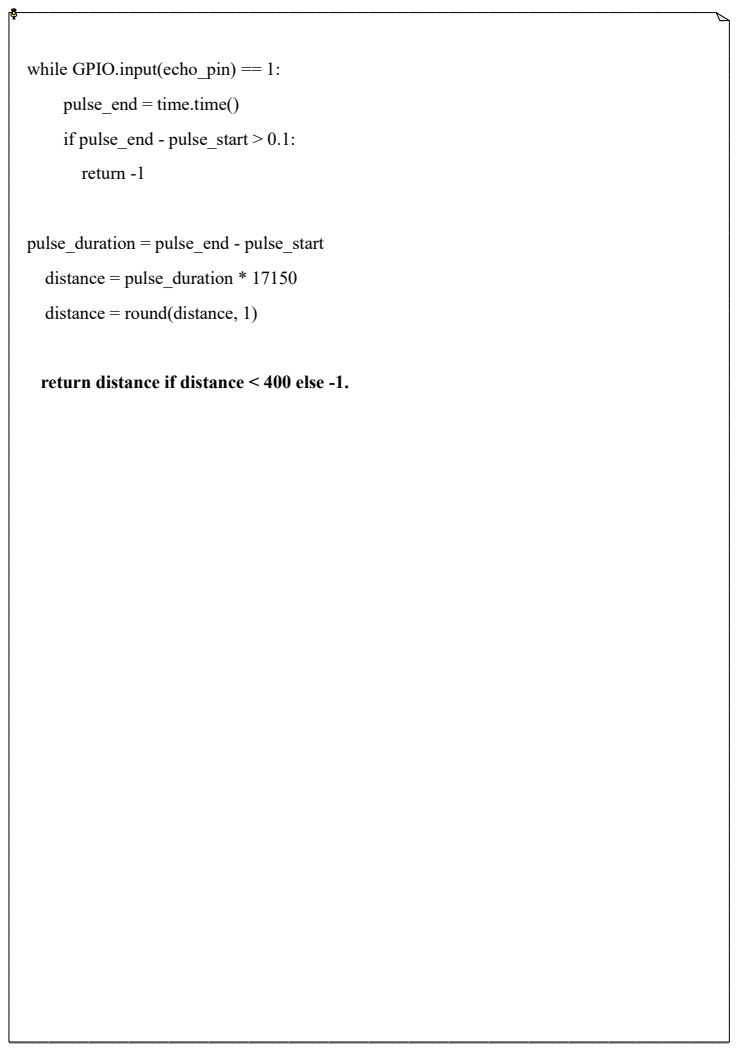
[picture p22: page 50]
pulse_end = time.time )(; if pulse_end - pulse_start > 0.1 :; return -1; pulse_duration = pulse_end - pulse_start; distance = pulse_duration * 17150

while GPIO.input(echo_pin) == 1 :

distance = round(distance, 1)

return distance if distance < 400 else -1.

for i in range :)10(

avg_left = sum(left_readings) / len(left_readings) if left_readings else 0

avg_right = sum(right_readings) / len(right_readings) if right_readings else 0

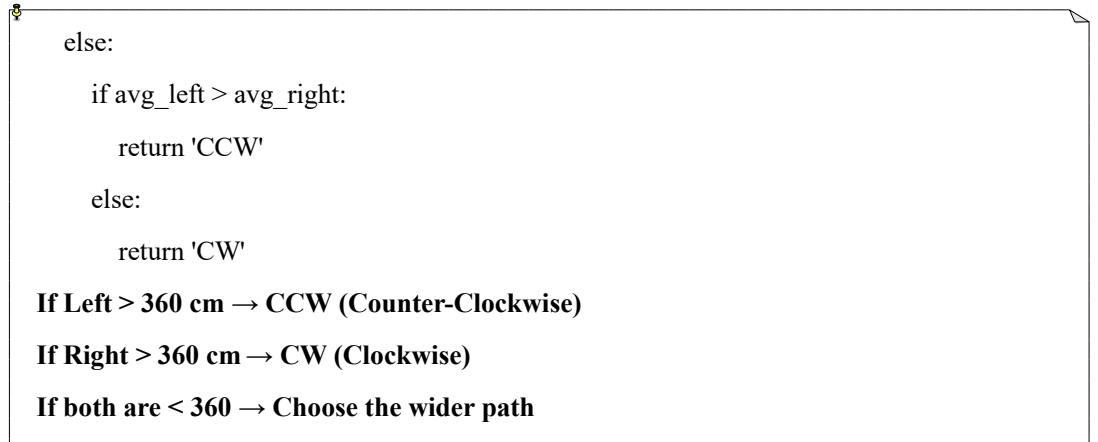
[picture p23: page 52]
else :; if avg_left > avg_right :; return 'CCW'; return 'CW '

If Left > 360 cm → CCW (Counter-Clockwise)

If Right > 360 cm → CW (Clockwise)

If both are < 360 → Choose the wider path

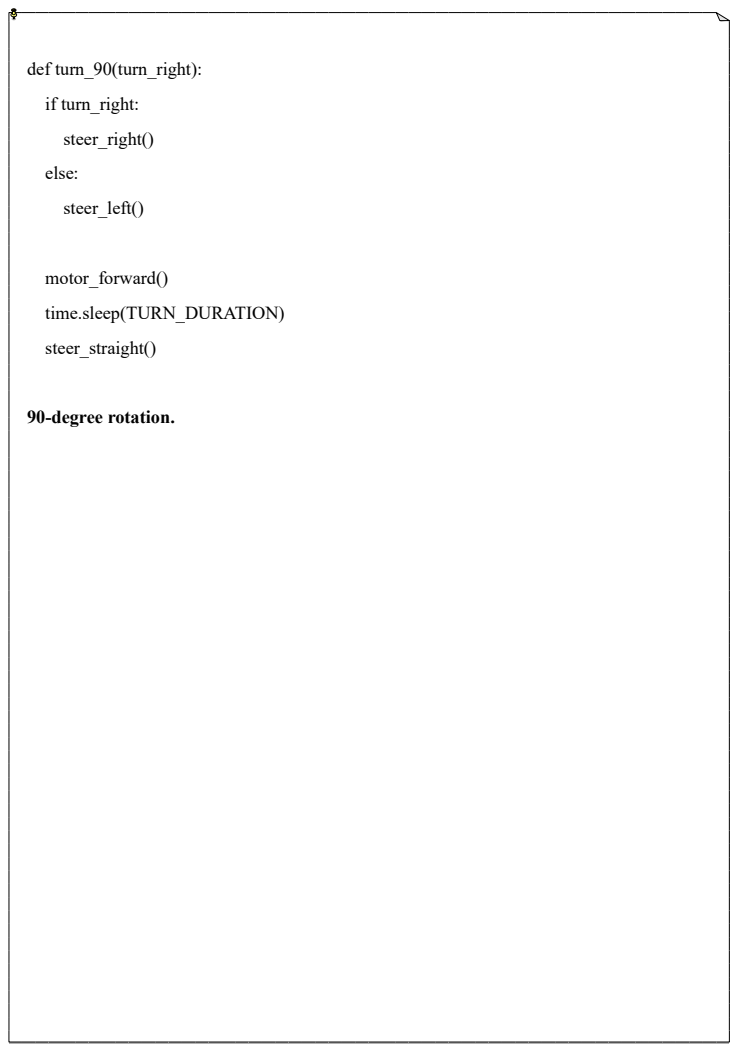
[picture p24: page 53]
def turn_90(turn_right) :; if turn_right :; steer_right )(; else :; steer_left )(; motor_forward )(; time.sleep(TURN_DURATION); steer_straight )(; 90-degree rotation.

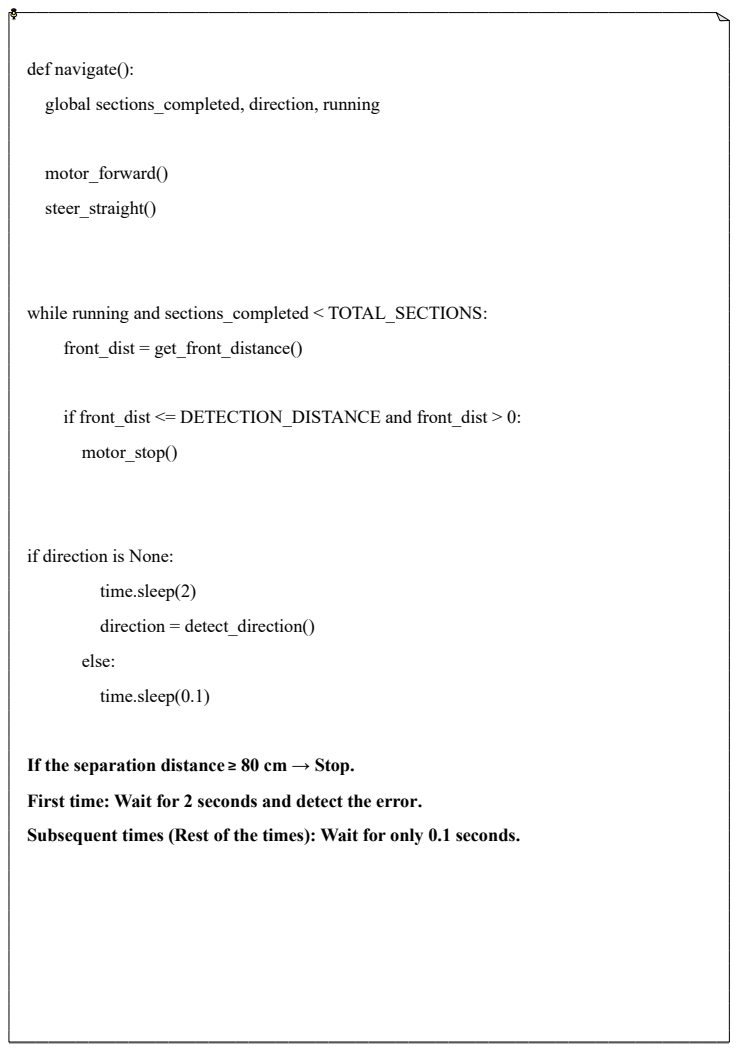
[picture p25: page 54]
def navigate():; motor_forward )(; steer_straight )(; front_dist = get_front_distance )(; if front_dist <= DETECTION_DISTANCE and front_dist > 0 :; motor_stop )(; time.sleep )2 (; direction = detect_direction )(; else :; time.sleep )0.1 (

global sections_completed, direction, running

while running and sections_completed < TOTAL_SECTIONS:

if direction is None :

If the separation distance ≥ 80 cm → Stop.

First time: Wait for 2 seconds and detect the error .

Subsequent times (Rest of the times): Wait for only 0.1 seconds.

The code begins to execute.

10) Obstacle Challenge Code:

This script uses the OpenCV (cv2) library to perform real-time color detection (specifically Red and Green) from a camera feed. It employs Gray World Color Normalization and the LAB color space to achieve robust detection regardless of varying lighting conditions .

import cv2

import numpy as np

def normalize_color(frame) :

""" Gray world color normalization to reduce lighting effect"""

result = frame.astype(np.float32)

avg_b = np.mean(result[:, :, 0])

avg_g = np.mean(result[:, :, 1])

avg_r = np.mean(result[:, :, 2])

avg_gray = (avg_b + avg_g + avg_r) / 3

result[:, :, 0] = np.minimum(result[:, :, 0] * (avg_gray / avg_b), 255)

result[:, :, 1] = np.minimum(result[:, :, 1] * (avg_gray / avg_g), 255)

result[:, :, 2] = np.minimum(result[:, :, 2] * (avg_gray / avg_r), 255)

return result.astype(np.uint8)

1 .normalize_color(frame) Function

1 .normalize_color(frame) Function

This function implements the Gray World color normalization algorithm to correct color casts caused by uneven lighting. It assumes that the average color of a scene should be gray .

- Conversion and Averaging: The frame is converted to float32. It calculates the mean intensity (avg_b, avg_g, avg_r) for each BGR channel and the overall average intensity (avg_gray) .
- Correction: Each channel's pixels are scaled by a factor of avg_gray/avg_channel. This adjusts channels that are too bright or too dim to match the expected gray mean .
- Clamping: np.minimum(..., 255) ensures the corrected values stay within the valid 0-255 range before converting back to uint8.

#Initialize camera (USB or Pi camera)

camera = cv2.VideoCapture )0(

camera.set )640 ,3(

camera.set )480 ,4(

while True :

ret, frame = camera.read )(

if not ret :

break

# Optional: normalize to reduce color cast from lighting

frame = normalize_color(frame)

Camera Initialization and Frame Capture

Initialization: Opens the default camera (0) and sets the resolution to 640 \times 480 .

Loop: The main loop continuously reads frames. ret is a boolean indicating successful read .

Normalization: The optional normalize_color() function is called to process the frame before color detection begins.

# Convert BGR to LAB

lab = cv2.cvtColor(frame, cv2.COLOR_BGR2LAB)

L, A, B = cv2.split(lab)

--- # Detect RED (A-channel is high for red, low for green)---

red_mask = cv2.inRange(A, 150, 255) # high A → red

green_mask = cv2.inRange(A, 0, 110) # low A → green

LAB Conversion and Color Masking

- LAB Conversion: The BGR frame is converted to the LAB color space. LAB is preferred as the Luminance channel is separate from the A (Green to Red) chromaticity channels, making color detection less sensitive to brightness variations. The A-channel is then used exclusively to detect Red and Green.
- Masking (A-Channel) :
- Red Mask: High values in the A-channel (150 to 255) are isolated to create the red_mask.
- Green Mask: Low values in the A-channel (0 to 110) are isolated to create the green_mask.

# Clean up noise

kernel = np.ones((5, 5), np.uint8)

red_mask = cv2.morphologyEx(red_mask, cv2.MORPH_OPEN, kernel)

green_mask = cv2.morphologyEx(green_mask, cv2.MORPH_OPEN, kernel)

# Find contours

contours_red, _ = cv2.findContours(red_mask, cv2.RETR_TREE, cv2.CHAIN_APPROX_SIMPLE)

contours_green, _ = cv2.findContours(green_mask, cv2.RETR_TREE, cv2.CHAIN_APPROX_SIMPLE)

Morphological Operations and Contour Finding

- Noise Cleanup (Opening): The morphological opening operation is applied to both masks. This operation (erosion followed by dilation) effectively removes small specks of noise and smooths the boundaries of the detected color regions .

- Contour Detection: cv2.findContours() identifies the boundaries of the white (detected color) regions in the cleaned-up binary masks.

# Draw bounding boxes for red

for c in contours_red :

area = cv2.contourArea(c)

if area > 400 :

x, y, w, h = cv2.boundingRect(c)

cv2.rectangle(frame, (x, y), (x + w, y + h), (0, 0, 255), 2)

cv2.putText(frame, "RED", (x, y - 10), cv2.FONT_HERSHEY_SIMPLEX, 0.6, (0, 0, 255), 2)

# Draw bounding boxes for green

for c in contours_green :

area = cv2.contourArea(c)

if area > 400 :

x, y, w, h = cv2.boundingRect(c)

cv2.rectangle(frame, (x, y), (x + w, y + h), (0, 255, 0), 2)

cv2.putText(frame, "GREEN", (x, y - 10), cv2.FONT_HERSHEY_SIMPLEX, 0.6, (0, 255, 0), 2)

Contour Filtering and Annotation

- Filtering: Contours with an area less than 400 pixels are ignored to prevent drawing boxes around minor noise .
- Bounding Box: For valid contours, cv2.boundingRect() calculates the smallest upright rectangle surrounding the contour (x, y, w, h) .
- Drawing: A rectangle and a text label are drawn on the original frame in the appropriate color (BGR format: Red = (0, 0, 255), Green = (0, 255, 0)).

# Display the output

cv2.imshow("Color Detection (LAB-based)", frame)

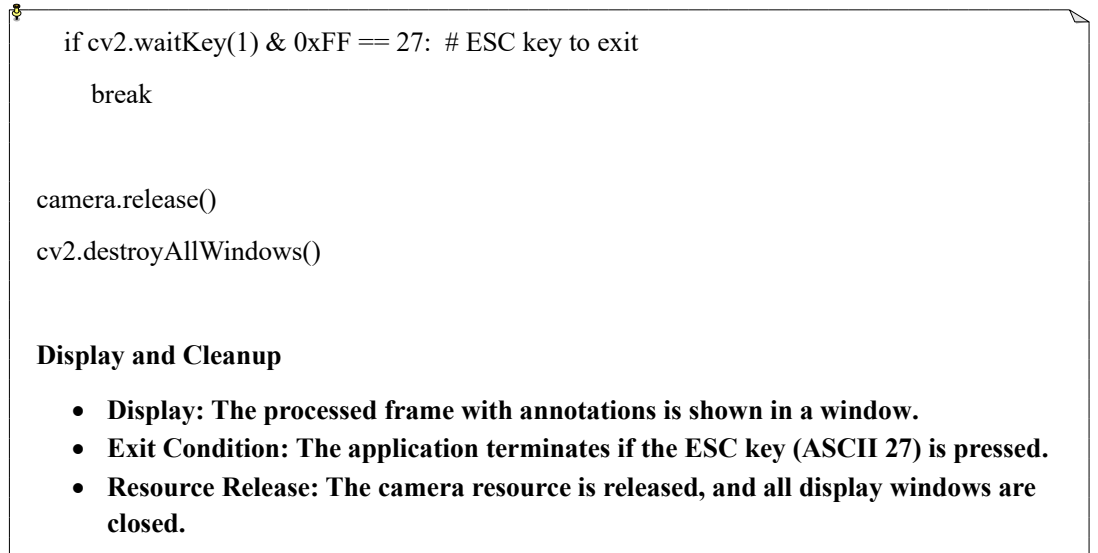
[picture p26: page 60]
break; camera.release )(; cv2.destroyAllWindows()

if cv2.waitKey(1) & 0xFF == 27: # ESC key to exit

Display and Cleanup

• Display: The processed frame with annotations is shown in a window .
• Exit Condition: The application terminates if the ESC key (ASCII 27) is pressed.
• Resource Release: The camera resource is released, and all display windows are
closed.

11) References and Applications Used:

During the development of our WRO robot project, we used several applications to design, plan, and present our work efficiently :

- Flowchart Design – BoardMix

We used BoardMix to create clear and organized flowcharts for our robot’s logic and program structure. This helped us plan the sequence of operations before writing the actual code .

- Circuit Design – Fritzing

Fritzing was used to design and visualize the electronic circuits of the robot. It allowed us to connect sensors, motors, and other components on a virtual breadboard before physical assembly .

- Presentation and Background – Canva

Canva was used to create professional backgrounds, diagrams, and visual materials for presentations and documentation, making our project visually appealing and easy to understand.

Here we document our work and projects step by step, as part of our participation in Future Engineers. We are a team of female students who work passionately to design and program innovative solutions that combine engineering, programming, and creativity Follow our repositories to learn about our progress and achievements.

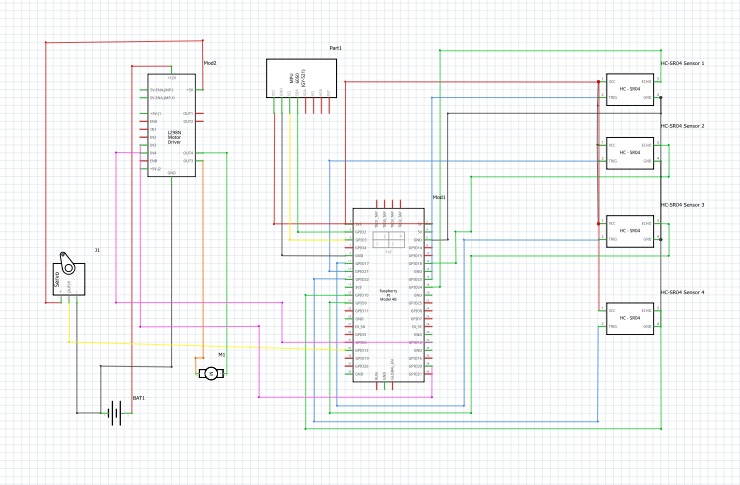
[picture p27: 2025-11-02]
Schemes/Electronic circuit wired.jpg

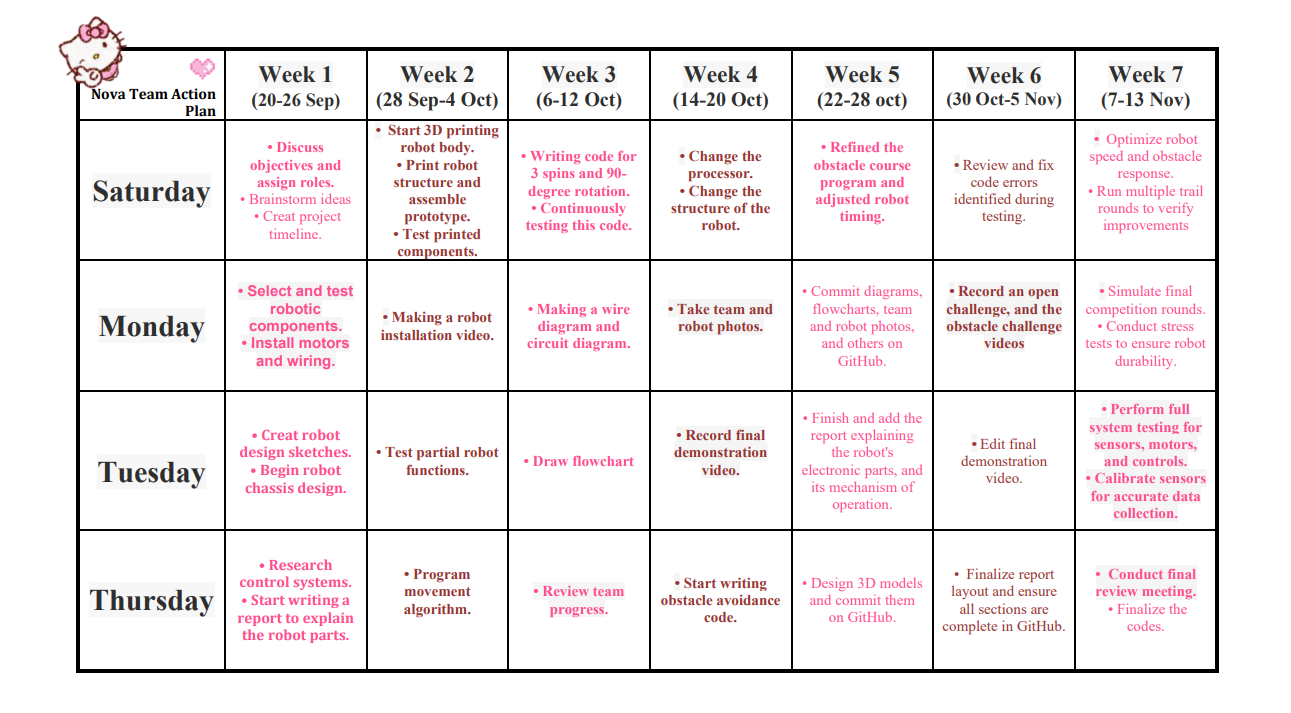
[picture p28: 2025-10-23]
Tables/Work Schedule type1.png.png

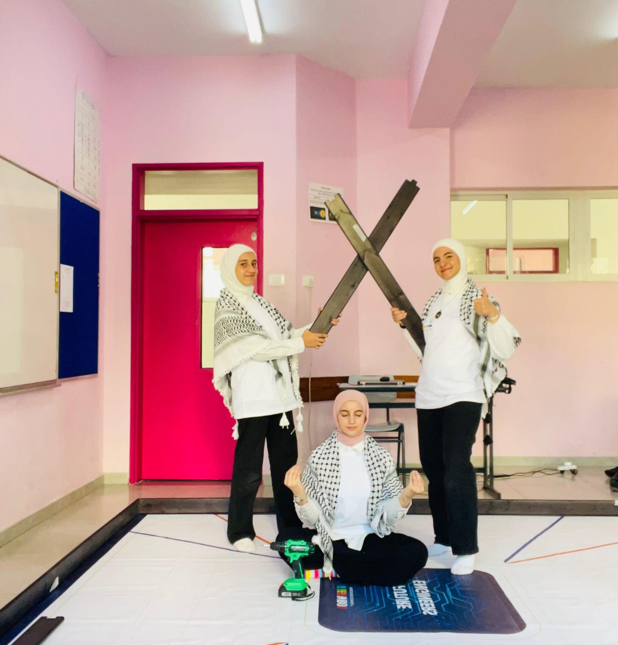
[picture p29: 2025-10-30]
Team-Photos/Funny photo.jpg

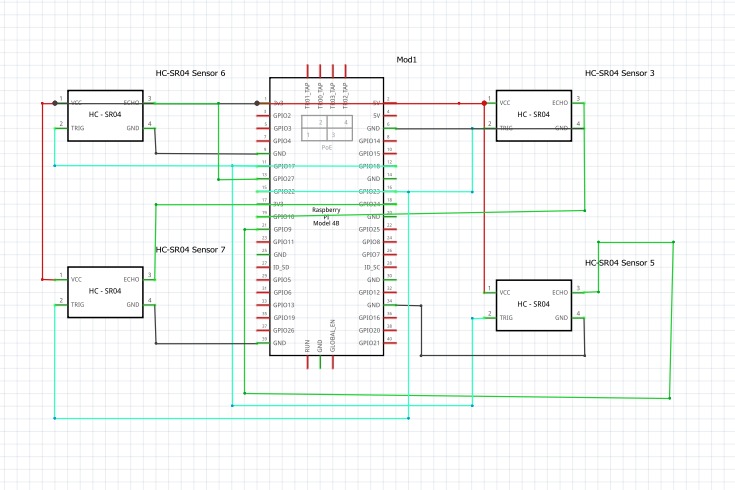
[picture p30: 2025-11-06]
Schemes/Ultrasonic.Wired.jpg

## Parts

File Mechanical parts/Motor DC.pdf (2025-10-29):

Motor DC

The DC Geared Motor provides the necessary mechanical power to drive the Single-Motor Rear-Wheel Drive (RWD) system. This component is a standard 9V DC motor with an integrated gearbox . The gear reduction is critical; it increases the motor’s torque significantly while reducing the output RPM, providing the crucial force needed for propulsion and enabling precise speed control at lower velocities. The motor is directly controlled by the 9V power output from the L298N Motor Driver, which utilizes PWM signals from the Raspberry Pi to modulate both speed and direction.

For efficient performance and to stay within the L298N driver's safe operating limits, the motor's current draw is estimated to be less than 1.5A under typical load. While specific torque and RPM values are often custom to the supplier, the motor is generally rated for approximately 300 RPM at 9V and provides sufficient torque (estimated cm) to manage the robot's mass and ٠at ~ 5-10 kg navigate the competition course

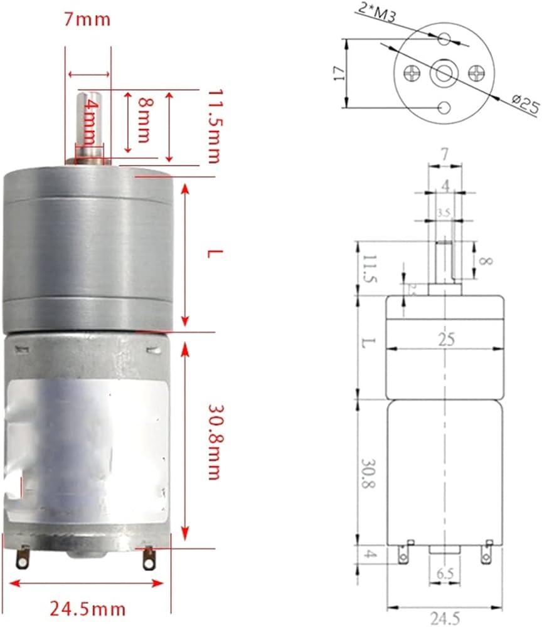
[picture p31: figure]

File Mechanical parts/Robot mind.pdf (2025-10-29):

Robot mind

The Raspberry Pi 4 Model B serves as the Main Processing Unit (MPU), acting as the robot’s central brain. It executes the complex Python code and coordinates all real-time sensory data and actuator commands.

We selected the Raspberry Pi 4 for its high-performance quad-core Cortex-A72 processor (1.8GHz) and 64-bit architecture. This computational power is non-negotiable, as it provides the necessary capacity to simultaneously manage:

- Computer Vision (CV): Processing real-time video frames from the USB Camera using the OpenCV library to detect and track colored obstacles.
- Sensor Fusion: Rapidly integrating data from the IMU (Gyroscope) and the four Ultrasonic Sensors for path correction and obstacle avoidance.
- In compliance with competition rules, the code is loaded onto the Raspberry Pi prior to the start. The entire autonomous routine is initiated by a physical push button connected to a GPIO pin, which activates the main Python script.

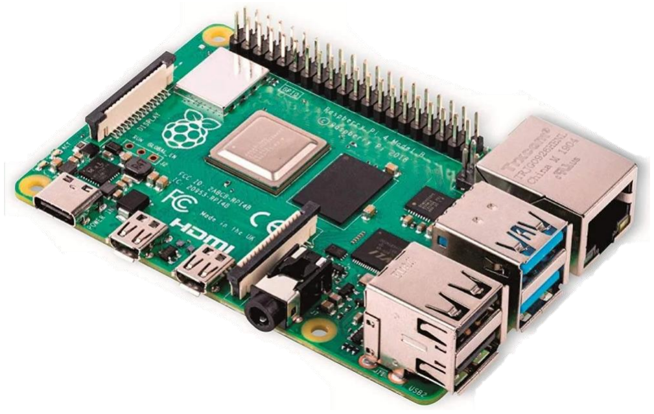
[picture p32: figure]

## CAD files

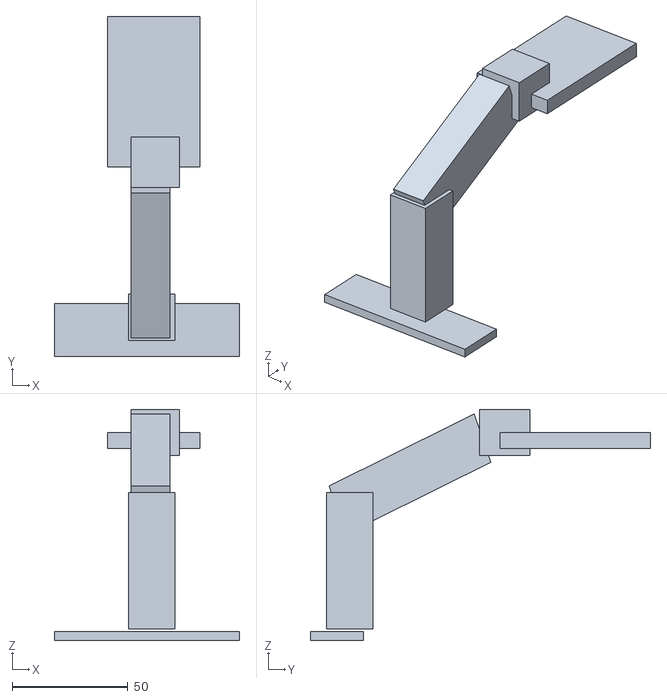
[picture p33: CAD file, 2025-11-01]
3D model/Cameraa.stl
80.0 x 147.0 x 100.0

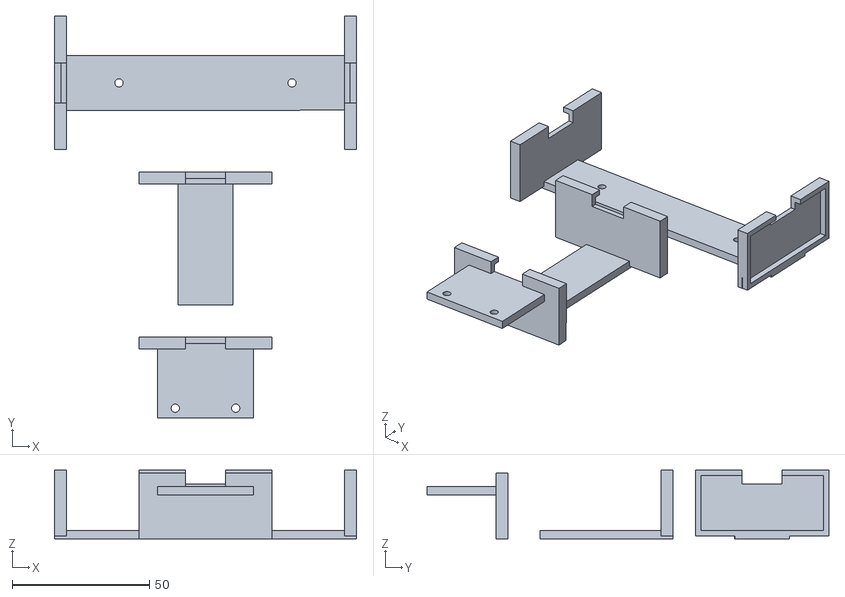
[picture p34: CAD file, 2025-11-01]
3D model/Ultrasonic Holder (1).stl
110.0 x 146.3 x 25.0

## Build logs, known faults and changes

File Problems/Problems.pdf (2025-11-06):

Problem: During robot operation, we noticed that the sensors were not stable enough, which led to inaccurate readings and negatively affected task performance.

Solution: We designed and installed a custom sensor mount using 3D printing, ensuring precise and secure placement of the sensors.

Benefits:

- Improved sensor accuracy.
- Reduced vibrations during robot movement.
- Enhanced structural and professional appearance of the robo

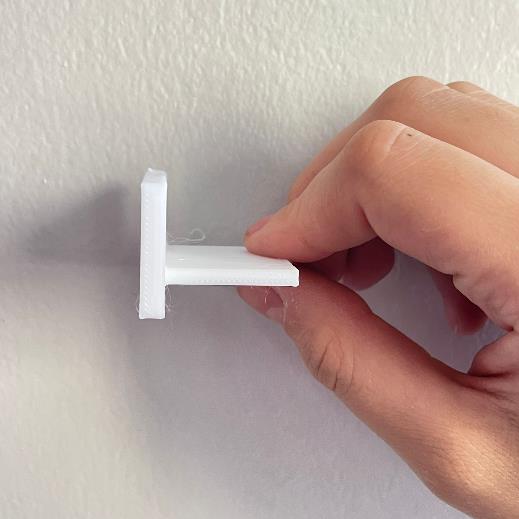
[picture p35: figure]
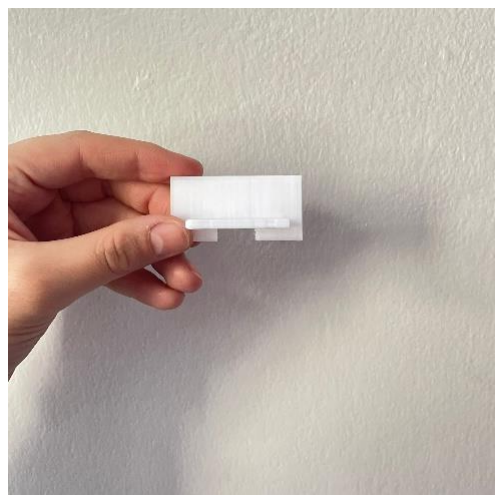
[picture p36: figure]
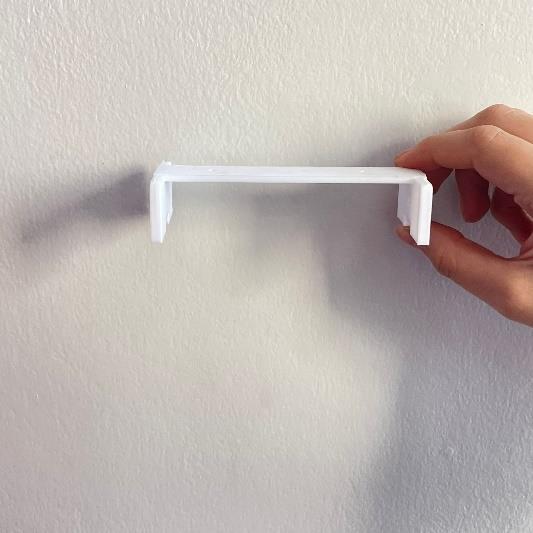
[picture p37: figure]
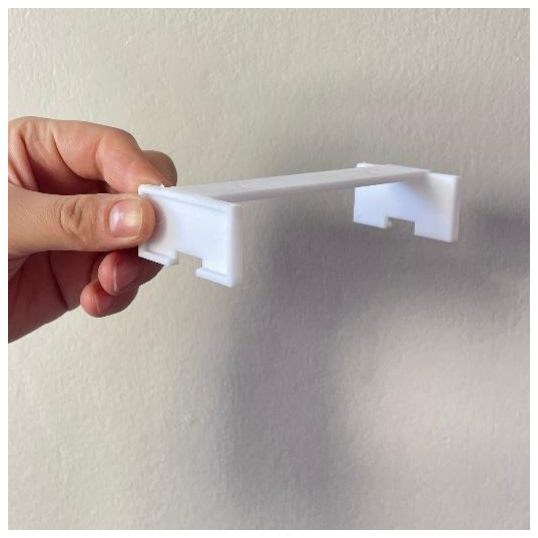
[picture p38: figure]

Problem: During robot testing, we noticed that the Control Device (SD0

was slow, causing delays in command execution and poor sensor responsiveness.

Solution: We replaced the unit with a new one featuring higher performance and faster processing speed, which significantly improved the robot’s responsiveness and task accuracy

Benefits:

- Faster execution of programmed commands.
- Better interaction with sensors and motors.
- Reduced errors caused by time delays.

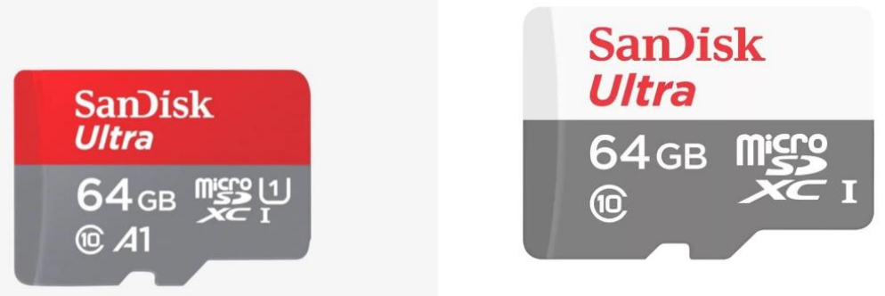
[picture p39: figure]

Old SD | New SD

Category | SD1 Old | SD 2 New
Model | SanDisk Ultra microSDXC | SanDiskUltra microSDXC A1
Capacity | 64GB | 64GB
Speed Class | Class 10 | Class 10
UHS Standard | UHS-1 | UHS-1
Application Performance Rating | None | A1 (Optimized for running applications
UHS Speed Rating | Not specified | U1(Minimum write speed 10MB/s
Performance with OS (e.g., Raspberry Pi) | Average | High performance optimized for system booting
Boot & App Loading Speed | Slower | Faster and more stable
Recommended Use | Basic file storage | Robotics OS running, Raspberry Pi, real-time tasks
Reason Not Selected | Can cause lag and slow loading | Chosen for stability, speed, and smooth robot performance

Problem:

While using the Raspberry Pi 4, we encountered several issues, including slow performance and unexpected system freezes. These problems affected the overall efficiency and reliability of our setup.

Solution:

To overcome these challenges, we upgraded our system to the Raspberry Pi 5, which offers improved processing power, better thermal management, and enhanced stability.

Benefits:

- Faster and more responsive performance
- Reduced system crashes and downtime
- Improved reliability and efficiency for continuous operation

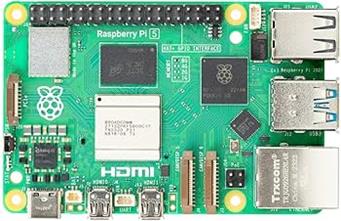
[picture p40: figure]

Problem:

At the beginning, we used a camera because it provided good performance and accurate detection. However, after modifying the robot’s engineering design and adding the 3D funnel, the camera no longer fit properly. Its position affected the field of view, which reduced its efficiency and response accuracy during movement.

Solution:

We decided to replace the camera with New Camera that better match the updated design and work effectively with the new 3D funnel structure. This allowed us to maintain reliable environmental sensing without compromising the robot’s mechanical design or functionality.

Benefits:

With this change, the robot achieved better integration between the mechanical structure and the electronic components. The new Camera setup worked efficiently and provided a clear detection path, improving overall performance, stability, and reducing technical issues caused by unsuitable camera placement.

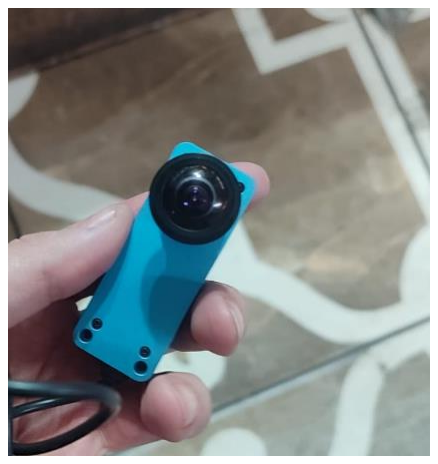
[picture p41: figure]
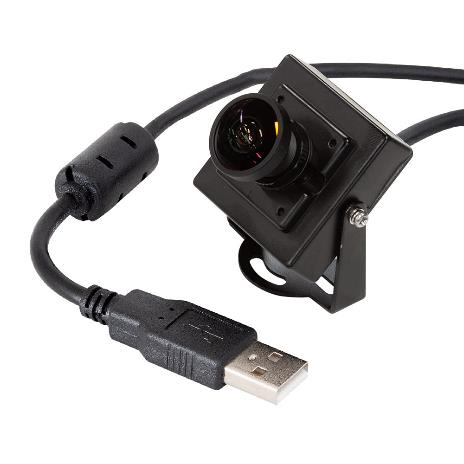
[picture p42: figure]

Old Camera | New Camera

Problem:

At the beginning of the project, we planned to use a color sensor to determine directions and guide the robot’s movement. However, we faced difficulties with color detection due to lighting changes and surface reflections in the competition environment. This affected the sensor’s accuracy and could cause the robot to make incorrect decisions.

Solution:

Instead of using the color sensor, we adopted a more reliable method by using the distance sensor. If the right sensor detects more than 160 cm, this means the robot should move counterclockwise. On the other hand, if the left sensor detects more than 160 cm, this means the robot should move clockwise. This approach allowed the robot to determine its direction accurately without relying on color detection.

Benefits:

This solution provided faster and more accurate direction control, making the robot less affected by lighting conditions or surface changes. It improved movement stability, enhanced performance, and increased reliability, helping the robot complete its path smoothly and efficiently.

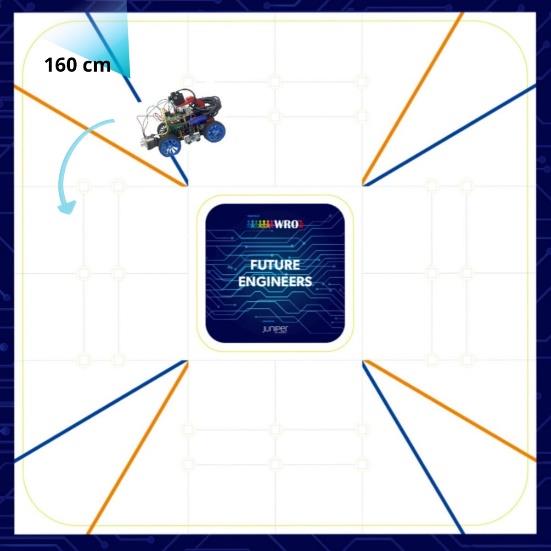
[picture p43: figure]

Problem:

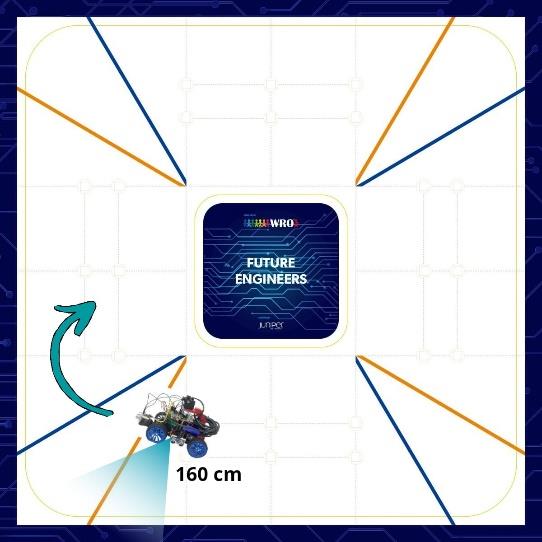
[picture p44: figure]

In the beginning, our robot relied only on the Ultrasonic sensor to determine its direction. However, we noticed that the robot sometimes drifted and did not stay perfectly on the intended path, especially when turning or moving for a long distance. This caused slight deviations that could affect its accuracy during the mission.

Solution:

To solve this issue, we added a gyroscope sensor alongside the distance sensor. The gyroscope helps the robot maintain a stable direction and corrects any drift by constantly monitoring the robot’s rotation angle. By combining both sensors, the robot can detect direction accurately and stay aligned with the path

Benefits:

With the gyroscope added, the robot became more stable and precise in its movements. It no longer drifts easily, and its turns became smoother and more controlled. This upgrade improved the overall performance, reliability, and accuracy of the robot during the competition missions

Problem: After installing the camera on the robot, we noticed it wasn’t securely fixed, which caused vibrations during movement and reduced image accuracy.

Solution: We designed a custom camera mount using 3D printing to ensure stable positioning and optimal viewing angle.

Benefits:

- Secure and stable camera installation.
- Improved image quality and visual processing.
- Easy adjustment of the camera angle when needed.

Problem:

We used to rely on time to make the robot complete three laps and return to the starting point. However, time-based control was not accurate, and small speed changes caused the robot to stop in the wrong location

Solution:

The robot sometimes missed the exact starting point because timing was not consistent. To solve this, we developed a new program that uses the distance sensor. When the sensor detects an obstacle or measures a distance greater than 160 cm, the robot counts one corner. After detecting 12 corners (3 laps), it stops precisely at the starting point

Benefits:

- More accurate return to the start point
- Stable and consistent performance

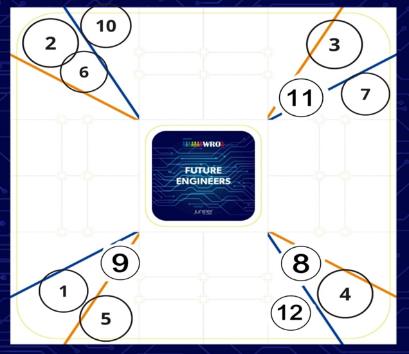
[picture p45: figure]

- Not affected by speed changes
- Higher precision and reliability

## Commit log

2025-09-26 الادوات المستخدمة
2025-09-27 اعضاء الفريق
2025-09-28 Update and rename فيديو توثيق تركيب السيارة.mp4 to Car documentation video
2025-09-28 Rename كود مجسم السيارة.jpg to 3D car model code.jpg
2025-09-28 Rename مرحلة تركيب 2.pdf to Installation stage.pdf
2025-10-23 Create Ultrasonic parts
    Add files
2025-10-23 Create CameraHandler.h
    add file
2025-10-23 Create 3D Printer.png
    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
2025-10-23 Create Work Schedule type1.png
    Attach the table
2025-10-23 Create Work Schedule type2.png
    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
2025-10-23 Create Work Schedule type3.png
    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
